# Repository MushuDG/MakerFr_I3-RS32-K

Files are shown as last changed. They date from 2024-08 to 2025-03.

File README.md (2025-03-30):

# 🚀 Upgrading the MakerFr I3-RS32: From SKR v1.4 to BTT Manta M5P + Klipper 🚀

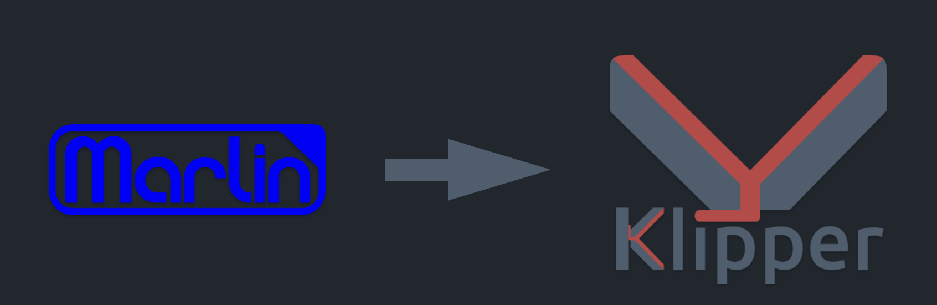
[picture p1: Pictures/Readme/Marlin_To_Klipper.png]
Marlin_To_Klipper


## 🌟 A Personal Note 🌟

Hey there, fellow 3D printing enthusiasts! 👋

After years of tinkering and printing with my trusty MakerFr I3-RS32 (an incredible Prusa like designed by RoMaker - [I3-RS32](https://www.makerfr.com/en/imprimante-3d/i3-rs32/presentation-de-la-i3rs32/)). I started to feel it was time for an upgrade. I’ve always loved tweaking my 3D printer, pushing its limits, and learning everything I can about the tech behind it. But lately, the SKR v1.4, while solid, just wasn’t cutting it anymore, and managing an external Raspberry Pi was getting... well, a bit cumbersome.

So, I decided it was time to dive into something new and exciting. I wanted a cleaner, more integrated setup, better performance, and—of course—a chance to dive deeper into the software side of things. That’s how this project was born: migrating from the SKR v1.4 to the **BTT Manta M5P** and switching from Marlin to **Klipper**. This isn’t just an upgrade; it’s a personal challenge to expand my skills and knowledge—and I’m excited to share this journey with you! 🎉

~ MushuDG

## Why Make the Switch? 🤔

1. **No More External Raspberry Pi! 🥳**

   - With the BTT Manta M5P, you get the power of a Raspberry Pi *built right in*. No more external boards cluttering up your setup—everything is clean and streamlined.
2. **Supercharge Your Firmware with Klipper 🚀**

   - Klipper isn’t just firmware—it’s a game-changer! Enjoy faster print speeds, higher precision, and advanced features that Marlin just can’t match. Discover what 3D printing can really do with Klipper’s real-time processing power.
3. **Simplified Setup & Greater Control 🎛️**

   - By upgrading to the Manta M5P, you’re moving to a modern, versatile board that simplifies your setup. And with Klipper, you’ll have unmatched control over your machine’s performance with a more intuitive configuration process.
4. **Future-Proof Your Printer 🔮**

   - The BTT Manta M5P is designed to support the latest innovations in 3D printing. This upgrade ensures that your MakerFr I3-RS32 stays ahead of the curve for years to come.
5. **A Learning Journey 🧠**

   - If you’re like me, you love to tinker and learn. This migration isn’t just about better prints—it’s about deepening your understanding of the software that drives your machine. Embrace the challenge and grow your skills!

## Parts and 3D Printed Parts 🛒

### Parts to Purchase

| Item | Price (USD) | Link |
|---|---|---|
| **BIGTREETECH Manta M5P** | ~$53.00 | [BIGTREETECH Manta M5P](https://biqu.equipment/products/manta-m4p-m8p?variant=40215552852066) |
| **BIGTREETECH CB1** | ~$30.00 | [BIGTREETECH CB1](https://biqu.equipment/products/manta-m4p-m8p?variant=39847241384034) |
| **BIGTREETECH CB1 Heatsink** | ~$5.50 | [BIGTREETECH CB1 Heatsink](https://biqu.equipment/products/manta-m4p-m8p?variant=39847241416802) |
| **Optional:** | | |
| **BIGTREETECH TFT35 SPI V2.1 Touch Screen** | ~$24.00 | [BIGTREETECH TFT35 SPI V2.1 Touch Screen](https://biqu.equipment/collections/lcd-screen/products/bigtreetech-tft35-spi-v2-1-touchscreen-io2can-module) |
| **Stylus for Touch Screen** | ~$1.10 | [Aliexpress Stylus](https://fr.aliexpress.com/item/1005006539716369.html?gatewayAdapt=glo2fra) |
| **Neopixel LEDs (1m 74 IP30 or 1m 144 IP30)** | ~$5.00| [Aliexpress Neopixel LEDs](https://fr.aliexpress.com/item/1005006224130239.html?gatewayAdapt=glo2fra) |
| **600mm SPI Cable** (choose Pitch 1.0mm; Direction Reverse; Length 600mm)  | ~$5.00| [eBay](https://www.ebay.fr/itm/253935636526?var=553252486969)

### 3D Printed Parts

| Item | Link |
|---|---|
| **Manta_M5P_Box.stl** | [Manta_M5P_Box.stl](https://github.com/MushuDG/MakerFr_I3-RS32-K/tree/main/STL) |
| **Manta_M5P_Cover.stl** | [Manta_M5P_Cover.stl](https://github.com/MushuDG/MakerFr_I3-RS32-K/tree/main/STL) |
| **Optional:** | |
| **TFT35-SPI.stl** | [TFT35-SPI.stl](https://github.com/MushuDG/MakerFr_I3-RS32-K/tree/main/STL) |
| **TFTholder.stl** | [TFTholder.stl](https://github.com/MushuDG/MakerFr_I3-RS32-K/tree/main/STL) |

## Ready to Dive In? 💻

In this documentation, I’ll guide you through the entire process—from hardware setup to firmware configuration. Whether you’re a seasoned maker or just curious, this guide has something for everyone. So, let’s get started and transform your 3D printing experience! 🔧✨

**Go to [Wiring](https://github.com/MushuDG/MakerFr_I3-RS32-K/blob/main/Documentation/1_Wiring.md)**

## 📜 License & Credits

This project is released under the **GNU General Public License v3.0**.

It includes modified code from the amazing project [Klipper Adaptive Meshing & Purging](https://github.com/kyleisah/Klipper-Adaptive-Meshing-Purging) by [@kyleisah](https://github.com/kyleisah), which is also licensed under **GPL-3.0**.

> Portions of the original code were adapted to fit the needs of this build, particularly in the context of bed mesh management and purge routines for the MakerFr I3-RS32 running Klipper.

Big kudos and thanks to Kyle for the original work and continued inspiration! 💜

---

**References:**

1. RoMaker. "[I3RS32 presentation](https://www.makerfr.com/en/imprimante-3d/i3-rs32/presentation-de-la-i3rs32/)." *MakerFr*.

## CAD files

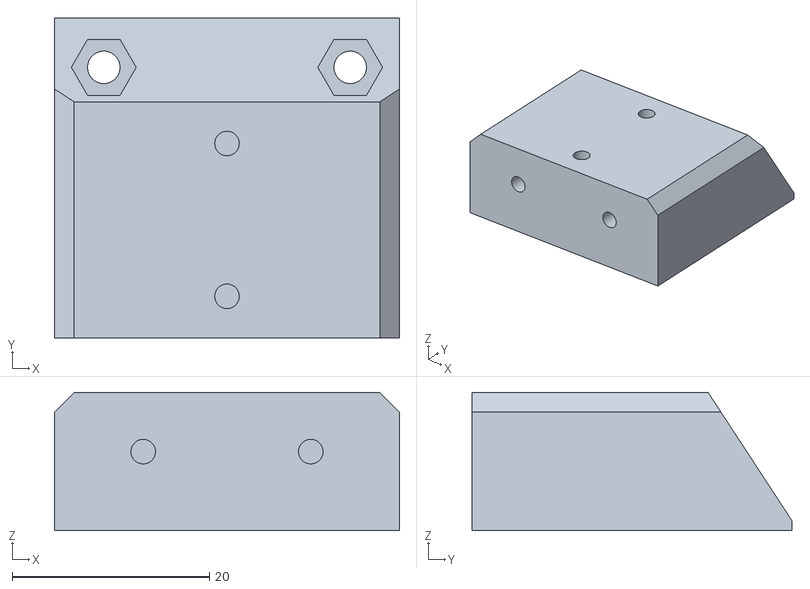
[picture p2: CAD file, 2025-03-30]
STL/BIQU_MicroProbe_holder.stl
35.0 x 32.5 x 14.0

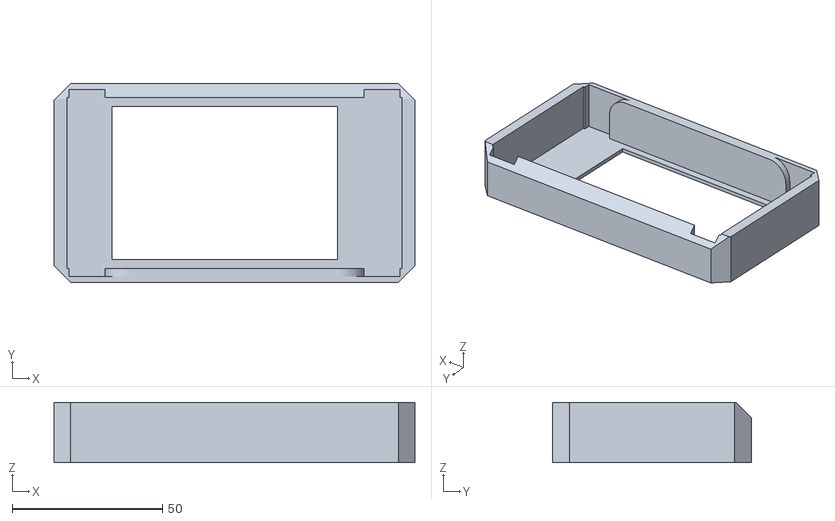
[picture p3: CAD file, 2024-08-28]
STL/TFT35-SPI.stl
120.0 x 66.0 x 20.0

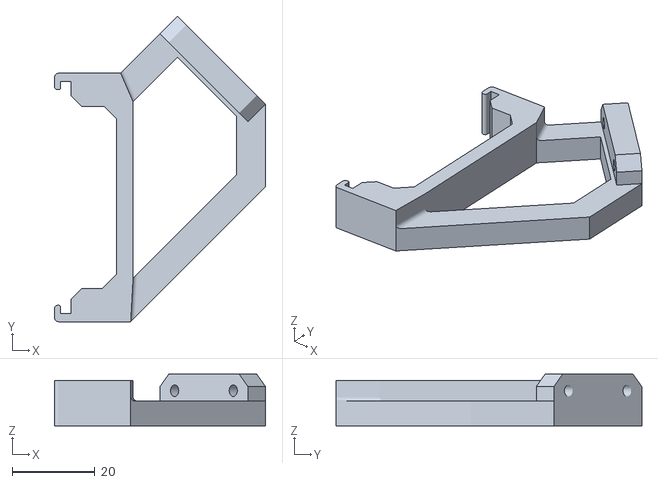
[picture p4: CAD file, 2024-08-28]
STL/TFTholder.stl
50.9 x 73.7 x 12.5

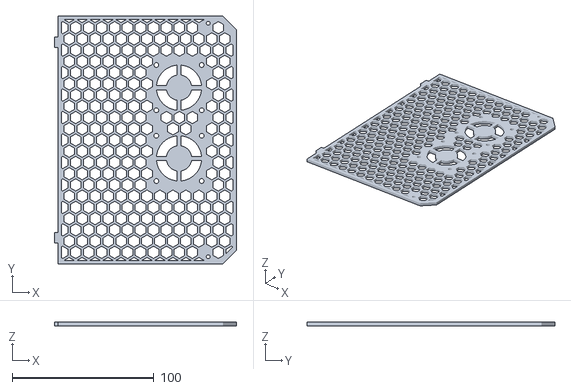
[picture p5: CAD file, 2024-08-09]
STL/Manta_M5P_Cover.stl
128.6 x 175.0 x 2.50

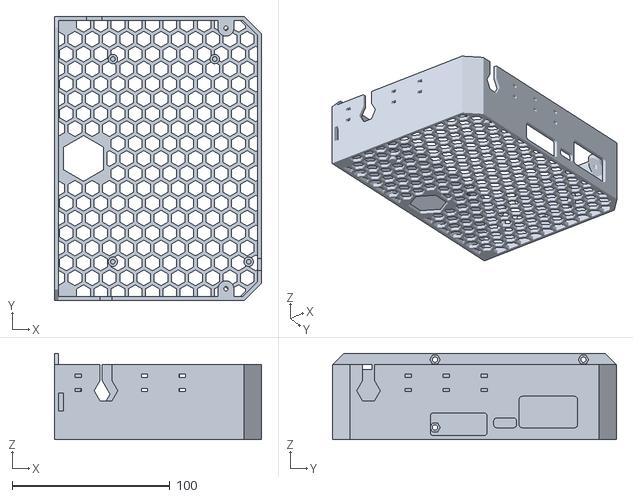
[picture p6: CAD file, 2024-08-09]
STL/Manta_M5P_Box.stl
131.1 x 180.0 x 54.7

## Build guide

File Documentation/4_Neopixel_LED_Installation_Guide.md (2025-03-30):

# 🌈 Neopixel LED Installation with Klipper on BTT Manta M5P

This guide will walk you through installing and configuring Neopixel LEDs on your BTT Manta M5P with Klipper. We’ll cover the physical installation, wiring, and configuring the Klipper firmware for dynamic LED control.

## Table of Contents
  1. [🔧 Materials Needed](#-materials-needed)
  2. [🛠️ Step 1: Physical Installation of LEDs](#️-step-1-physical-installation-of-leds)
  3. [🖥️ Step 2: Klipper Configuration for LEDs](#️-step-2-klipper-configuration-for-leds)
  4. [🚀 Step 3: Installing Klipper-LED\_Effect Plugin](#-step-3-installing-klipper-led_effect-plugin)
  5. [✅ Step 4: Testing and Verifying LED Installation](#-step-4-testing-and-verifying-led-installation)
  6. [📚 References](#-references)

## 🔧 Materials Needed

- **Neopixel LEDs** – *We used Black PCB, 1m 74 IP30, but feel free to choose your desired density (e.g., 144 LEDs/m).*
- **Wires** – *Three wires for power, ground, and signal.*
- **Soldering Kit** – *Ensure to solder correctly, following the directional arrow on the PCB!*
- **Connector JST** – *For connecting to the Manta board.*
- **BTT Manta M5P** – *Your baseboard where the LEDs will be connected.*

## 🛠️ Step 1: Physical Installation of LEDs

1. **Unboxing and Preparing LEDs**: Start by preparing your Neopixel LEDs. You can use 74 LEDs/m or opt for 144 LEDs/m for a more consistent lighting effect.
2. **Wiring and Soldering**: Solder the three wires to the LED strip, ensuring to follow the directional arrow on the PCB that indicates signal direction. 
    - **Common mistake**: Don’t solder on the wrong side (the direction of the arrow is crucial). 
3. **Connecting to the Manta Board**: 
    - Use a **JST connector** to hook up the LEDs directly to the **RGB1 port** of the Manta board:
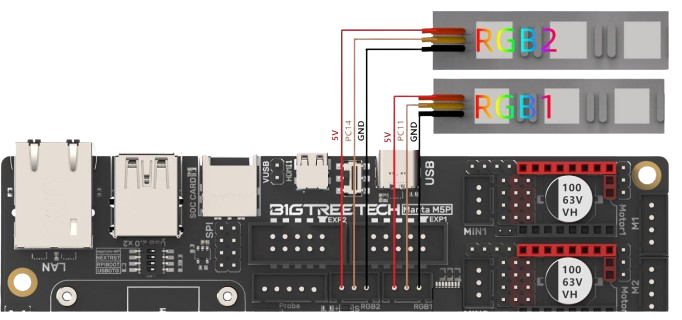
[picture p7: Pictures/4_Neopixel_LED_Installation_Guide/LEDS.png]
Manta_M5P_LEDS_Wiring


## 🖥️ Step 2: Klipper Configuration for LEDs

1. **Download the Configuration File**: Download the `leds.cfg` from this [GitHub link](https://raw.githubusercontent.com/MushuDG/MakerFr_I3-RS32-K/refs/heads/main/Klipper_Config/components_config/leds.cfg) and place it in the `~/printer_data/config/` directory.
2. **Edit printer.cfg**: 
    - In your `printer.cfg`, include the line `[include leds.cfg]` to load the LED configuration file. Uncomment this line by removing the `#`.
3. **Configure the LED settings**: In the `leds.cfg` file, adjust the following parameters:
    - **Pin**: Specify the pin depending on where the LEDs are connected. Use `PC11` for **RGB1** and `PC14` for **RGB2**.
    - **Chain Count**: Specify the number of LEDs in your chain. For example, `chain_count: 22`.

    ```ini
    pin: PC11  # Pin connected to the Neopixel LEDs.
    chain_count: 22  # Number of Neopixels in the chain.
    ```

## 🚀 Step 3: Installing Klipper-LED_Effect Plugin

1. **SSH into Your CB1**: Open a terminal and SSH into your CB1 board.
2. **Run the following commands** to clone and install the Klipper-LED_Effect plugin:

    ```bash
    cd ~
    git clone https://github.com/julianschill/klipper-led_effect.git
    cd klipper-led_effect
    ./install-led_effect.sh
    ```

3. **Configure LED Effects**: Follow the instructions in the Klipper-LED_Effect repository to set up and customize various LED effects.

## ✅ Step 4: Testing and Verifying LED Installation

1. **Restart Klipper**: Once everything is installed, restart Klipper for the changes to take effect.
2. **Test LED Operation**: Use commands in the Klipper console to check if the LEDs are functioning correctly. Adjust the effects or configurations as needed.
3. **Troubleshooting**: If the LEDs don’t light up or behave unexpectedly, double-check the wiring and ensure that the `leds.cfg` file is correctly configured.

Happy printing with your glowing setup! 🌟

**Optional: Go to [BTT TFT35 SPI installation](https://github.com/MushuDG/MakerFr_I3-RS32-K/blob/main/Documentation/5_BTT_TFT35_Installation_Guide.md)**

## 📚 References
1. [Klipper LED Effects Plugin Documentation](https://github.com/julianschill/klipper-led_effect)
2. [BTT Manta M5P Documentation](https://github.com/bigtreetech/Manta-M5P)

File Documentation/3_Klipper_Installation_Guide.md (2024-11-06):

# 🚀 Klipper Installation Guide via KIAUH

This guide will walk you through installing Klipper on your BTT CB1 with a BTT Manta M5P using KIAUH (Klipper Installation And Update Helper). Let's get started!

## Table of Contents
- [🚀 Klipper Installation Guide via KIAUH](#-klipper-installation-guide-via-kiauh)
  - [Table of Contents](#table-of-contents)
  - [🎯 Prerequisites](#-prerequisites)
  - [🛠️ Step 1: SSH into Your Machine](#️-step-1-ssh-into-your-machine)
  - [🧰 Step 2: Install Git](#-step-2-install-git)
  - [📥 Step 3: Clone the KIAUH Repository](#-step-3-clone-the-kiauh-repository)
  - [🚀 Step 4: Launch KIAUH](#-step-4-launch-kiauh)
  - [🔧 Step 5: Install Klipper](#-step-5-install-klipper)
  - [🌑 Step 6: Install Moonraker](#-step-6-install-moonraker)
  - [💧 Step 7: Install Fluidd](#-step-7-install-fluidd)
  - [🔧 Step 8: Configure Klipper](#-step-8-configure-klipper)
  - [🌐 Step 9: Access Fluidd](#-step-9-access-fluidd)
  - [⚙️ Step 10: Configure Fluidd for Klipper](#️-step-10-configure-fluidd-for-klipper)
  - [🔄 Step 11: Reboot and Test](#-step-11-reboot-and-test)
    - [Home Axes + Bed Mesh Calibration:](#home-axes--bed-mesh-calibration)
    - [Z-Tilt:](#z-tilt)
    - [PID Calibration for Hotend:](#pid-calibration-for-hotend)
    - [PID Calibration for Bed:](#pid-calibration-for-bed)
  - [🛠️ Step 12: Adjust the Z-Offset Using `PROBE_CALIBRATE`](#️-step-12-adjust-the-z-offset-using-probe_calibrate)
    - [Step 12.1: Open the Fluidd Interface](#step-121-open-the-fluidd-interface)
    - [Step 12.2: Start the Probe Calibration](#step-122-start-the-probe-calibration)
    - [Step 12.3: Adjust the Z-Offset](#step-123-adjust-the-z-offset)
    - [Step 12.4: Save the Calibration](#step-124-save-the-calibration)
    - [Step 12.5: Test the New Z-Offset](#step-125-test-the-new-z-offset)
  - [🛠️ Step 13: Calibrating Extruder Rotation Distance](#️-step-13-calibrating-extruder-rotation-distance)
    - [Initial Setup](#initial-setup)
    - [Step-by-Step Calibration](#step-by-step-calibration)
    - [Important Note](#important-note)
  - [🛠️ Step 14: Configuring Slicer](#️-step-14-configuring-slicer)
  - [References 📚](#references-)

## 🎯 Prerequisites

Before we begin, ensure you have the following:

- **BTT CB1 + BTT Manta M5P**: Your hardware should be set up and running a compatible Linux-based OS.
- **SSH Access**: Make sure SSH is enabled and you can connect to your system.

## 🛠️ Step 1: SSH into Your Machine

First, connect to your BTT CB1 via SSH:

```bash
ssh <username>@<IP_of_your_BTT_CB1>
```

Replace `<username>` with your actual username and `<IP_of_your_BTT_CB1>` with the IP address of your BTT CB1.

## 🧰 Step 2: Install Git

Ensure Git is installed on your machine:

```bash
sudo apt-get update
sudo apt-get upgrade
sudo apt-get install git -y
```

## 📥 Step 3: Clone the KIAUH Repository

Next, clone the KIAUH repository:

```bash
git clone https://github.com/th33xitus/kiauh.git
cd kiauh
```

## 🚀 Step 4: Launch KIAUH

Run KIAUH to open the installation menu:

```bash
./kiauh.sh
```

## 🔧 Step 5: Install Klipper

1. Select `Install Klipper` from the menu using `1` and `1` in the `[ Installation Menu ]`.
2. Select your preferred Python version. Use `1` for the recommended setting.
3. Select the number of Klipper instances to set up. The number of Klipper instances will determine the amount of printers you can run from the host. Select `1` to install 1 instance.

## 🌑 Step 6: Install Moonraker

1. From the `Installation Menu`, type `1` to start the installation process.
2. Select `2 [Moonraker]` to install Moonraker.
3. Enter `Y` to confirm the installation.

## 💧 Step 7: Install Fluidd

1. From the `Installation Menu`, type `1` to start the installation process.
2. Select `4 [Fluidd]` to install Fluidd.
3. Enter `Y` to confirm the installation.
4. Enter `Y` again when prompted to install the recommended macros.

## 🔧 Step 8: Configure Klipper

1. From the main menu, use `4` to enter the `Advanced Menu`.
2. Type `2` to enter the Klipper firmware building setup.
3. Enter these parameters:

```bash
[*] Enable extra low-level configuration options
    Micro-controller Architecture (STMicroelectronics STM32) --->
    Processor model (STM32G0B1) --->
    Bootloader offset (8KiB bootloader) --->
    Clock Reference (8 MHz crystal) --->
    Communication interface (USB (on PA11/PA12)) --->
```

4. Type `q` to quit and save the config. The building step will automatically be launched.
5. Type `3` in the `Advanced Menu`.
6. Type `1` to use the regular flashing method.
7. Type `1` to use `make flash`.
8. Type `1` to install in USB mode.
9. Enter your available MCU number and enter `Y` to continue.

   **Note:** After the writing is completed, there will be an error message: `dfu-util: Error during download get_status`, just ignore it.

## 🌐 Step 9: Access Fluidd

After everything is set up, you can access Fluidd from your web browser:

```http
http://<IP_of_your_BTT_CB1>
```

Replace `<IP_of_your_BTT_CB1>` with the actual IP address of your BTT CB1.

## ⚙️ Step 10: Configure Fluidd for Klipper

To configure Klipper with Fluidd, follow these steps:

1. Download the base configuration files:
   - [printer.cfg](https://github.com/MushuDG/MakerFr_I3-RS32-K/tree/main/Klipper_Config/base/printer.cfg)
   - [bed_mesh.cfg](https://github.com/MushuDG/MakerFr_I3-RS32-K/tree/main/Klipper_Config/base/bed_mesh.cfg)
   - [input_shaping.cfg](https://github.com/MushuDG/MakerFr_I3-RS32-K/tree/main/Klipper_Config/base/input_shaping.cfg)
   - [macros.cfg](https://github.com/MushuDG/MakerFr_I3-RS32-K/tree/main/Klipper_Config/base/macros.cfg)
   - [sensors.cfg](https://github.com/MushuDG/MakerFr_I3-RS32-K/tree/main/Klipper_Config/base/sensors.cfg)
   - [steppers.cfg](https://github.com/MushuDG/MakerFr_I3-RS32-K/tree/main/Klipper_Config/base/steppers.cfg)

2. Choose and download the configuration files for your specific components from the **components_config** folder:
   - [leds.cfg](https://github.com/MushuDG/MakerFr_I3-RS32-K/tree/main/Klipper_Config/components_config/leds.cfg) (if using Neopixel LEDs)
   - [tft35-v3.cfg](https://github.com/MushuDG/MakerFr_I3-RS32-K/tree/main/Klipper_Config/components_config/tft35-v3.cfg) (if using the BTT TFT35-V3.0 screen)
   - [tmc2208.cfg](https://github.com/MushuDG/MakerFr_I3-RS32-K/tree/main/Klipper_Config/components_config/tmc2208.cfg) (if using TMC2208 drivers)
   - [tmc2209.cfg](https://github.com/MushuDG/MakerFr_I3-RS32-K/tree/main/Klipper_Config/components_config/tmc2209.cfg) (if using TMC2209 drivers)

3. Upload the **printer.cfg** and all relevant included configuration files (including your chosen component files) to the following directory on your BTT CB1:
   ```bash
   /home/biqu/printer_data/config/
   ```

4. Make sure to adapt the `printer.cfg` file to your setup:
   - Adjust the `[mcu]` section with the correct serial ID of your MCU.
   - Include or comment out the relevant `include` statements based on your chosen hardware from the **components_config** directory.

   Example from `printer.cfg`:

   ```ini
   [include bed_mesh.cfg]
   [include input_shaping.cfg]
   [include macros.cfg]
   [include sensors.cfg]
   [include steppers.cfg]
   #[include leds.cfg]        # Uncomment if using Neopixel LEDs
   #[include tft35-v3.cfg]    # Uncomment if using BTT TFT35-V3.0 screen
   #[include tmc2208.cfg]     # Uncomment if using TMC2208 drivers
   [include tmc2209.cfg]      # Comment out if using TMC2208 drivers
   ```

5. To find your MCU serial ID, use this command via SSH:

   ```bash
   ls /dev/serial/by-id
   ```

6. Install KAMP in a `ssh` environment with the following command:
   ```bash
    cd
   
    git clone https://github.com/kyleisah/Klipper-Adaptive-Meshing-Purging.git
   
    ln -s ~/Klipper-Adaptive-Meshing-Purging/Configuration printer_data/config/KAMP

    cp ~/Klipper-Adaptive-Meshing-Purging/Configuration/KAMP_Settings.cfg ~/printer_data/config/KAMP_Settings.cfg
   ```
7. Open your `moonraker.conf` file and add this configuration:
   ```ini
   [update_manager Klipper-Adaptive-Meshing-Purging]
   type: git_repo
   channel: dev
   path: ~/Klipper-Adaptive-Meshing-Purging
   origin: https://github.com/kyleisah/Klipper-Adaptive-Meshing-Purging.git
   managed_services: klipper
   primary_branch: main
   ```

8. Open `KAMP_Settings.cfg` file delete and paste following content:
   ```ini
   [include ./KAMP/Adaptive_Meshing.cfg]       # Include to enable adaptive meshing configuration.
   #[include ./KAMP/Line_Purge.cfg]             # Include to enable adaptive line purging configuration.
   #[include ./KAMP/Voron_Purge.cfg]            # Include to enable adaptive Voron logo purging configuration.
   #[include ./KAMP/Smart_Park.cfg]             # Include to enable the Smart Park function, which parks the printhead near the print  area for final heating.

   [gcode_macro _KAMP_Settings]
   description: This macro contains all adjustable settings for KAMP 

   # The following variables are settings for KAMP as a whole.
   variable_verbose_enable: True               # Set to True to enable KAMP information output when running. This is useful for  debugging.

   # The following variables are for adjusting adaptive mesh settings for KAMP.
   variable_mesh_margin: 10                     # Expands the mesh size in millimeters if desired. Leave at 0 to disable.
   variable_fuzz_amount: 0                     # Slightly randomizes mesh points to spread out wear from nozzle-based probes. Leave at    0 to disable.

   # The following variables are for those with a dockable probe like Klicky, Euclid, etc.                 # ----------------  Attach  Macro | Detach Macro
   variable_probe_dock_enable: False           # Set to True to enable the usage of a dockable probe.      #   ---------------------------------------------
   variable_attach_macro: 'Attach_Probe'       # The macro that is used to attach the probe.               # Klicky Probe:    'Attach_Probe' | 'Dock_Probe'
   variable_detach_macro: 'Dock_Probe'         # The macro that is used to store the probe.                # Euclid Probe:    'Deploy_Probe' | 'Stow_Probe'
                                                                                                           # Legacy Gcode:    'M401'         | 'M402'

   # The following variables are for adjusting adaptive purge settings for KAMP.
   variable_purge_height: 0.8                  # Z position of nozzle during purge, default is 0.8.
   variable_tip_distance: 20                    # Distance between tip of filament and nozzle before purge. Should be similar to    PRINT_END final retract amount.
   variable_purge_margin: 60                   # Distance the purge will be in front of the print area, default is 10.
   variable_purge_amount: 30                   # Amount of filament to be purged prior to printing.
   variable_flow_rate: 12                      # Flow rate of purge in mm3/s. Default is 12.

   # The following variables are for adjusting the Smart Park feature for KAMP, which will park the printhead near the print area at a    specified height.
   variable_smart_park_height: 10              # Z position for Smart Park, default is 10.

   gcode: # Gcode section left intentionally blank. Do not disturb.

       {action_respond_info(" Running the KAMP_Settings macro does nothing, it is only used for storing KAMP settings. ")}

   ```

9. Once all files are uploaded and configured, restart Klipper and Fluidd from the web interface.

## 🔄 Step 11: Reboot and Test

Finally, reboot your BTT CB1 to ensure everything is set up correctly. After rebooting, test your setup by sending a command to your 3D printer via Fluidd.

You can test with the following commands:

### Home Axes + Bed Mesh Calibration:
```gcode
G28
BED_MESH_CALIBRATE
SAVE_CONFIG
```

### Z-Tilt:
```gcode
G28
Z_TILT_ADJUST
```

### PID Calibration for Hotend:
```gcode
PID_CALIBRATE HEATER=extruder TARGET=205
```

### PID Calibration for Bed:
```gcode
PID_CALIBRATE HEATER=heater_bed TARGET=65
```

## 🛠️ Step 12: Adjust the Z-Offset Using `PROBE_CALIBRATE`

Setting the correct Z-offset is crucial for achieving a perfect first layer. Here’s how to do it using the `PROBE_CALIBRATE` command directly from the Fluidd interface.

### Step 12.1: Open the Fluidd Interface

1. Access your Fluidd interface via your web browser.
2. Navigate to the **Console** tab.

### Step 12.2: Start the Probe Calibration

In the console, initiate the probe calibration process by entering:

```gcode
PROBE_CALIBRATE
```

This command will begin the process by homing the printer and then moving the probe to the center of the bed.

### Step 12.3: Adjust the Z-Offset

Once the probe is positioned, the nozzle will move down toward the bed. You need to manually adjust the Z-offset using the following command:

```gcode
TESTZ Z=-0.1
```

Keep sending the `TESTZ` command with small negative increments (e.g., `Z=-0.1`) until the nozzle is at the perfect distance from the bed. Use a piece of paper as a feeler gauge—when you feel slight resistance while moving the paper, you've found the correct offset.

### Step 12.4: Save the Calibration

After finding the right Z-offset, save the configuration with:

```gcode
ACCEPT
SAVE_CONFIG
```

The `ACCEPT` command will finalize the Z-offset setting, and `SAVE_CONFIG` will write this setting to your `printer.cfg` file.

### Step 12.5: Test the New Z-Offset

Finally, test your new Z-offset by printing a small test print to ensure the first layer adheres correctly. If further adjustments are needed, repeat the above steps.

## 🛠️ Step 13: Calibrating Extruder Rotation Distance

The `rotation_distance` of an extruder is the distance that the filament travels during one complete rotation of the stepper motor. To get this setting just right, it’s best to use a "measure and adjust" method. Here’s how:

### Initial Setup

1. **Estimate the Rotation Distance:** Start with an initial estimate of the `rotation_distance`. You can derive this from `steps_per_mm` or by inspecting your hardware.
   
2. **Prepare Your Printer:**
   - Make sure the extruder is loaded with filament.
   - Heat the hotend to the appropriate temperature.
   - Ensure your printer is ready to extrude.

### Step-by-Step Calibration

1. **Mark the Filament:**
   - Use a marker to place a mark on the filament approximately 70 mm from where it enters the extruder.
   - Use digital calipers to measure the exact distance from the mark to the extruder entrance. Record this as `initial_mark_distance`.

2. **Extrude Filament:**
   - In your printer’s console, run the following commands to extrude 50 mm of filament:
     ```
     G91
     G1 E50 F60
     ```
   - Record 50 mm as `requested_extrusion_distance`.
   - Wait for the extruder to complete the movement (about 50 seconds). Using a slow speed is crucial for accuracy, as faster speeds may cause high pressure, distorting your results. (Avoid using graphical interface extrude buttons for this test—they extrude too quickly.)

3. **Measure the Result:**
   - Use the calipers again to measure the new distance from the extruder entrance to the mark on the filament. Record this as `final_mark_distance`.
   - Calculate the actual amount extruded:  
     `actual_extrusion_distance = initial_mark_distance - final_mark_distance`

4. **Update the Rotation Distance:**
   - Calculate the new `rotation_distance` using:  
     `new_rotation_distance = previous_rotation_distance * actual_extrusion_distance / requested_extrusion_distance`
  - Round the new `rotation_distance` to three decimal places.

5. **Repeat if Necessary:**
   - If the `actual_extrusion_distance` differs from the `requested_extrusion_distance` by more than 2 mm, repeat the steps above to refine your calibration.

### Important Note

Avoid using the "measure and adjust" method for calibrating X, Y, or Z axes. This method isn’t precise enough for those axes and may lead to a suboptimal setup. For those, measure your belts, pulleys, and lead screws instead.

## 🛠️ Step 14: Configuring Slicer
1. Download and install the prusaslicer [I3-RS32 preset](https://github.com/MushuDG/MakerFr_I3-RS32-K/blob/main/PrusaSlicer_Config/I3-RS32-K_config_bundle.ini).

🎉 Congratulations! You've successfully installed Klipper on your BTT CB1 with a BTT Manta M5P using KIAUH. Enjoy the enhanced performance and capabilities Klipper brings to your 3D printing experience!

**Optional: Go to [Neopixel LEDs Installation Guide](https://github.com/MushuDG/MakerFr_I3-RS32-K/blob/main/Documentation/4_Neopixel_LED_Installation_Guide.md)**

## References 📚
1. [BigTreeTech Manta M5P Documentation](https://github.com/bigtreetech/Manta-M5P)
2. [Klipper3D Documentation](https://www.klipper3d.org)
3. RoMaker. "[I3RS32 settings](https://www.makerfr.com/imprimante-3d/i3-rs32/reglages-i3-rs32/)." *MakerFr*.

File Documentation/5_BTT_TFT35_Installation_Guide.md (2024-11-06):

# 🖥️ Integration of BTT TFT35 SPI V2.1 with BTT Manta M5P

This guide will help you successfully connect and configure your **BTT TFT35 SPI V2.1** touch screen with the **BTT Manta M5P**. We’ll go over the hardware setup, cabling, and software configuration, including calibration tips to avoid ghost touches.

## Table of Contents
- [🖥️ Integration of BTT TFT35 SPI V2.1 with BTT Manta M5P](#-integration-of-btt-tft35-spi-v21-with-btt-manta-m5p)
  - [🔧 Materials Needed](#-materials-needed)
  - [🛠️ Step 1: Hardware Installation](#%EF%B8%8F-step-1-hardware-installation)
  - [🔌 Step 2: Cable Length and Ghost Touch Issues](#-step-2-cable-length-and-ghost-touch-issues)
  - [📁 Step 3: Installing KlipperScreen](#-step-3-installing-klipperscreen)
  - [⚙️ Step 4: Screen Calibration](#%EF%B8%8F-step-4-screen-calibration)
  - [📚 References](#-references)

## 🔧 Materials Needed

1. **BTT TFT35 SPI V2.1 Touch Screen** – *This is the touch screen we will be using.*
2. **BTT Manta M5P Board** – *Your mainboard.*
3. **600mm SPI Cable** – *I recommend using a 600mm cable to avoid ghost touch issues due to interference.*
4. **Screwdriver, Wires, and Connectors** – *Standard tools for wiring and connection.*

## 🛠️ Step 1: Hardware Installation

1. **Mount the TFT35 Screen**: Securely mount the **TFT35 SPI V2.1** screen to your printer’s frame.
2. **Wiring**: Connect the screen to the **BTT Manta M5P** using the **SPI Screen** ports on both the screen and the board.
   - Use a **600mm SPI cable** to reduce the risk of interference (see the note below for more details on cable length).

## 🔌 Step 2: Cable Length and Ghost Touch Issues

When using a longer SPI cable (over 600mm), some users have reported **ghost touch issues**, which are caused by signal interference. To avoid this problem, it's best to stick to a **600mm cable**. If you need one, here is a recommended source:
- **600mm SPI Cable**: [eBay Link](https://www.ebay.fr/itm/253935636526?var=553252486969)

This should fix most interference issues.

## 📁 Step 3: Installing KlipperScreen

Once the hardware is set up and the screen is calibrated, we need to configure it in **Klipper**. **KIAUH** (Klipper Installation and Update Helper) makes it easy to install and configure KlipperScreen.

1. **SSH into your CB1**: Open a terminal and connect to your CB1 using SSH.
2. **Install KlipperScreen**:
    - Run the following command to start **KIAUH**:
    ```bash
    ./kiauh/kiauh.sh
    ```
    - In the main menu, type `1` to open the **Install Menu**, and type `5` to install KlipperScreen.
    - The tool will automate the process. Once completed, you'll see a success message.
3. **Restart Klipper**: After installation, restart Klipper, and you should see the TFT35 screen interface.

## ⚙️ Step 4: Screen Calibration

To improve the touch accuracy and avoid any ghost touches, it's important to **calibrate your screen**. Follow this official tutorial from **BTT** for calibrating your TFT35 SPI screen:

1. login into your CB1 via SSH
2. Install `xinput_calibrator`
```bash 
sudo apt update
sudo apt install xinput-calibrator
```
3. Query the ID of the touchscreen, The name of TFT35_SPI is ns2009 or TSC2007, as shown in the figure bellow the id is 6
```bash
DISPLAY=:0 xinput_calibrator --list
```
tft35_spi_id

4. Start calibration, Click on the center of the cross that appears one by one on the screen. Replace the id with the actual id found in the previous step. Record the parameters of `click 0 X`, `click 0 Y`, `click 3 X`, and `click 3 Y`, which are required for conversion.
```bash
DISPLAY=:0 xinput_calibrator -v --device <id>
```
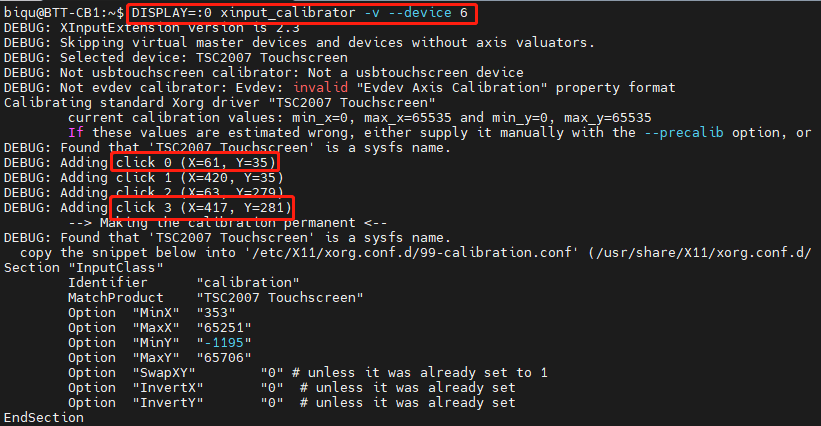
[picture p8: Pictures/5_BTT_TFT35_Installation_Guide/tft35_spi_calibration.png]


5. **!!! WARNING:** The parameter of `xinput_calibrator` cannot be directly used for `libinput` and needs to be converted. Please refer to here for details:
6. Create conversion script:
```bash
sudo nano libinput_calibrator.sh
```
7. Copy and paste the following content:

```bash
#!/bin/bash

#according to https://wiki.archlinux.org/title/Talk:Calibrating_Touchscreen#Libinput%5Fbreaks%5Fxinput%5Fcalibrator

screen_width=$1
screen_height=$2
click_0_X=$3
click_0_Y=$4
click_3_X=$5
click_3_Y=$6

re='^[0-9]+$'
if ! [[ $screen_width =~ $re ]] ; then
  echo "error: screen_width=\"$screen_width\" Not a number" >&2; exit 1
fi
if ! [[ $screen_height =~ $re ]] ; then
  echo "error: screen_height=\"$screen_height\" Not a number" >&2; exit 1
fi
if ! [[ $click_0_X =~ $re ]] ; then
  echo "error: click_0_X=\"$click_0_X\" Not a number" >&2; exit 1
fi
if ! [[ $click_0_Y =~ $re ]] ; then
  echo "error: click_0_Y=\"$click_0_Y\" Not a number" >&2; exit 1
fi
if ! [[ $click_3_X =~ $re ]] ; then
  echo "error: click_3_X=\"$click_3_X\" Not a number" >&2; exit 1
fi
if ! [[ $click_3_Y =~ $re ]] ; then
  echo "error: click_3_Y=\"$click_3_Y\" Not a number" >&2; exit 1
fi

#a = (screen_width * 6 / 8) / (click_3_X - click_0_X)
#c = ((screen_width / 8) - (a * click_0_X)) / screen_width
#e = (screen_height * 6 / 8) / (click_3_Y - click_0_Y)
#f = ((screen_height / 8) - (e * click_0_Y)) / screen_height

a=$(awk "BEGIN { printf(\"%.6f\", ($screen_width * 6 / 8) / ($click_3_X - $click_0_X))}")
c=$(awk "BEGIN { printf(\"%.6f\", (($screen_width / 8) - ($a * $click_0_X)) / $screen_width)}")
e=$(awk "BEGIN { printf(\"%.6f\", ($screen_height * 6 / 8) / ($click_3_Y - $click_0_Y))}")
f=$(awk "BEGIN { printf(\"%.6f\", (($screen_height / 8) - ($e * $click_0_Y)) / $screen_height)}")

CONFIG_OPTION="Option \"CalibrationMatrix\" "
CONFIG_LINE="\"$a 0.000000 $c 0.000000 $e $f 0.000000 0.000000 1.000000\""

echo "${CONFIG_OPTION}${CONFIG_LINE}"
echo ""

CONFIG_OPTION="Option \"CalibrationMatrix\" "
CONFIG="/usr/share/X11/xorg.conf.d/40-libinput.conf"
INPUT_CLASS="Identifier \"libinput touchscreen catchall\""
if [ -e "${CONFIG}" ]; then
    ks_restart=0
    grep -e "^\        ${CONFIG_OPTION}${CONFIG_LINE}" ${CONFIG} > /dev/null
    STATUS=$?
    if [ $STATUS -eq 1 ]; then
        sudo sed -i "/${CONFIG_OPTION}/d" ${CONFIG}
        sudo sed -i "/${INPUT_CLASS}/a\        ${CONFIG_OPTION}${CONFIG_LINE}" ${CONFIG}
        echo "Written to file:"
        echo "    ${CONFIG}"
        echo ""
        ks_restart=1
    fi

    # restart KlipperScreen
    if [ ${ks_restart} -eq 1 ];then
        sudo service KlipperScreen restart
    fi

    echo "run:"
    echo "    DISPLAY=:0 xinput list-props <device>"
    echo "to check if the calibration parameters are effective"
    echo ""
fi

```

8. Add executable permissions
```bash
sudo chmod +x libinput_calibrator.sh
```

9. Run the script with previous values in argument (got on point 4):

```bash
sudo ./libinput_calibrator.sh <screen width> <screen height> <click_0 X> <click_0 Y> <click_3 X> <click_3 Y>

```
Replace <arguments> with following values:
`<screen width>`: Screen horizontal resolution, TFT35 SPI is `480`
`<screen height>`: Screen vertical resolution, TFT35 SPI is `320`
`<click_0 X>`: The `X` position of `click 0` during the previous step calibration
`<click_0 Y>`: The `Y` position of `click 0` during the previous step calibration
`<click_3 X>`: The `X` position of `click 3` during the previous step calibration
`<click_3 Y>`: The `Y` position of `click 3` during the previous step calibration

for example:
```bash
sudo ./libinput_calibrator.sh 480 320 61 35 417 281
```

## 📚 References

1. [BTT TFT35 SPI V2.1 Documentation](https://bttwiki.com/tft35_spi_v2.1.html)
2. [BTT Manta M5P Documentation](https://github.com/bigtreetech/Manta-M5P)
3. [600mm SPI Cable on eBay](https://www.ebay.fr/itm/253935636526?var=553252486969)
4. [BTT Screen Calibration Guide](https://bttwiki.com/libinput_calibration.html)
5. [KlipperScreen Installation Guide](https://www.obico.io/blog/klipper-screen/)

Feel free to ask any questions or report issues in the [MakerFR forum](https://www.makerfr.com/forum/viewtopic.php?t=14710). Happy printing with your new touchscreen setup! 😊

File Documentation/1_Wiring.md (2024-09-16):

# 🛠️ MakerFr I3-RS32-K Wiring Guide

This guide will help you correctly connect all components to ensure your 3D printer functions optimally. Remember to double-check every connection before powering up, particularly the polarities, to avoid any potential damage. ⚠️

## Table of Contents
1. [Wiring Overview](#wiring-overview)
   - [Connection Table](#connection-table)
2. [Important Note 📌](#important-note-)
3. [Display Wiring](#display-wiring)
4. [Jumpers Configuration 🔧](#jumpers-configuration-)
   - [UART Mode of TMC Driver](#uart-mode-of-tmc-driver)
   - [Driver Voltage Selection](#driver-voltage-selection)
   - [CNC Fan Voltage Selection](#cnc-fan-voltage-selection)
5. [Additional Steps ✅](#additional-steps-)
6. [References 📚](#references-)

## Wiring Overview

Refer to the following diagram for the overall wiring layout:

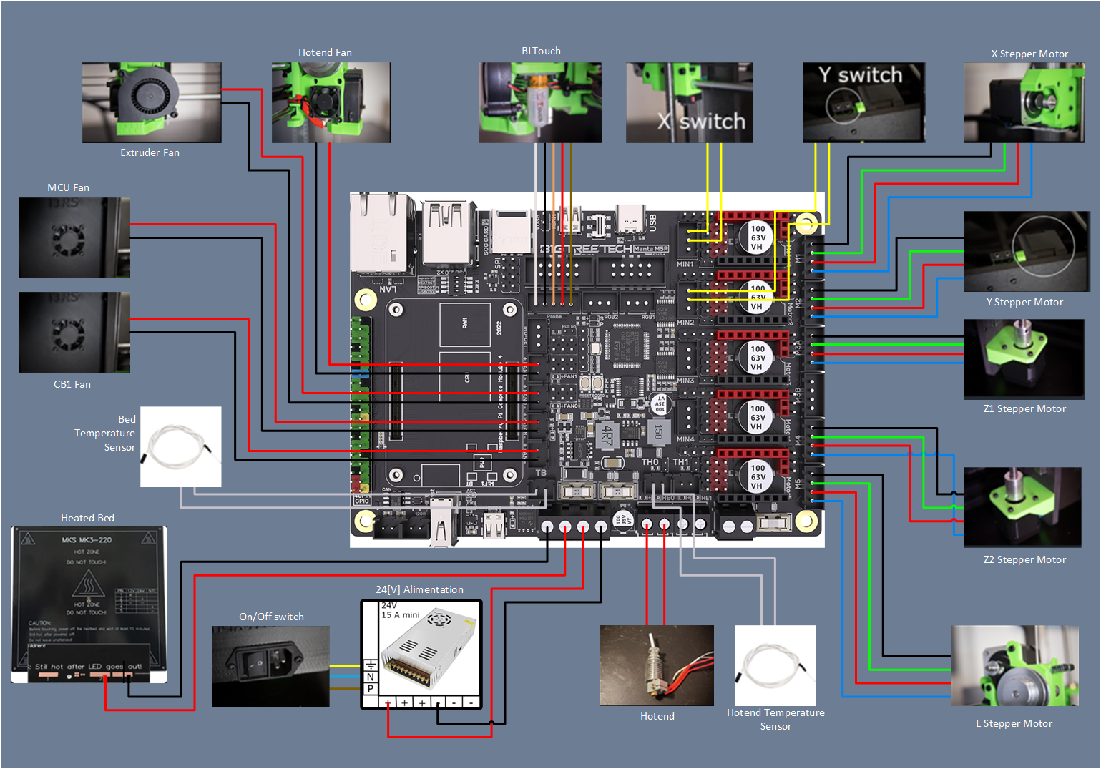
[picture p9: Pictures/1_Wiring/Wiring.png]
Manta_M5P_Wiring


### Connection Table

The table below provides detailed information on each connection point, including the pin or port, the connected component, its function, and the corresponding pinout.

| Pin/Port | Connected Component | Description | Pinout |
| --- | --- | --- | --- |
| **M1** | Motor 1 (X-Axis) | Stepper motor for X-Axis movement | PA15 (EN), PB9 (STEP), PC6 (DIR), PD9 (CS) |
| **M2** | Motor 2 (Y-Axis) | Stepper motor for Y-Axis movement | PA13 (EN), PA10 (STEP), PA14 (DIR), PB9 (CS)  |
| **M3A** | Motor 3A (Z-Axis) | Stepper motor for Z-Axis (Left) | PA9 (EN), PC7 (STEP), PC8 (DIR), PD8 (CS) |
| **M4** | Motor 4 (Z-Axis) | Stepper motor for Z-Axis (Right) | PA8 (EN), PB12 (STEP), PB11 (DIR), PB2 (CS) |
| **M5** | Motor 5 (Extruder) | Stepper motor for the extruder | PC4 (EN), PB0 (STEP), PB1 (DIR), PA6 (CS) |
| **MIN1** | X switch | Endstop switch for X-Axis | PD3 (GND), PA3 (5V), PA2 (Signal) |
| **MIN2** | Y switch | Endstop switch for Y-Axis | PD5 (GND), PA4 (5V), PA1 (Signal) |
| **HE0** | Hotend Heater | Heats the filament for extrusion | PA5 (VBB), PA7 (GND) |
| **TH0** | Hotend Thermistor | Measures the temperature of the hotend | PA1 (Signal), GND |
| **TB** | Bed Thermistor | Measures the temperature of the heated bed | PA0 (Signal), GND |
| **HV-IN**  | Power Input | 24V Power supply connection | HV+, HV- |
| **FAN0** | Part Cooling Fan | Fan for cooling the printed part | VBB (Power), PF3 (GND) |
| **FAN1** | Hotend Cooling Fan | Fan for cooling the hotend | VBB (Power), PF4 (GND) |
| **+FAN-**  | Electronics Cooling Fan | Fan for cooling the mainboard electronics  | VBB (Power), PF5 (GND) |
| **PI-FAN** | CB1 Cooling Fan | Fan for cooling the CB1 | VBB (Power), PF6 (GND) |
| **Probe**  | BLTouch | Used for automatic bed leveling | PA11 (Signal), PC15 (GND), PA6 (5V) |
| **HB** | Bed Heater | Power for the heated bed | PA5 (VBB), PA7 (GND) |

### Important Note 📌

The colors of the cables in the diagram can generally be trusted. However, the color order of stepper motor cables may vary depending on the manufacturer. Please ensure that the color sequence of your stepper motors matches the diagram or the pinout provided.

### Display Wiring

Connect the two EXP ports (EXP1, EXP2) to the TFT35 as shown in the diagram below:

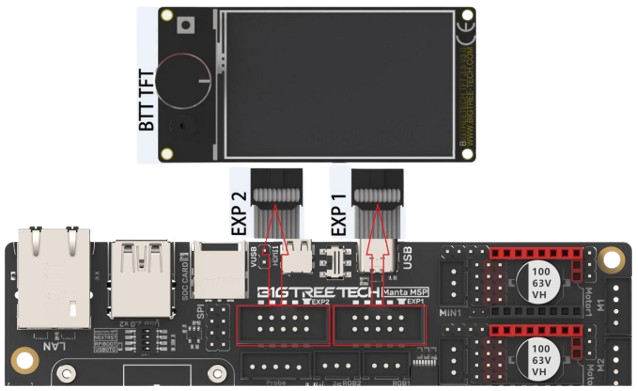
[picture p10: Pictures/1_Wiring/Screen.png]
Screen


## Jumpers Configuration 🔧

### UART Mode of TMC Driver

If you're using TMC2208, TMC2209, TMC2225, or similar drivers, ensure the jumpers are placed as shown in the diagram below. The microsteps and current settings can be configured within the firmware.

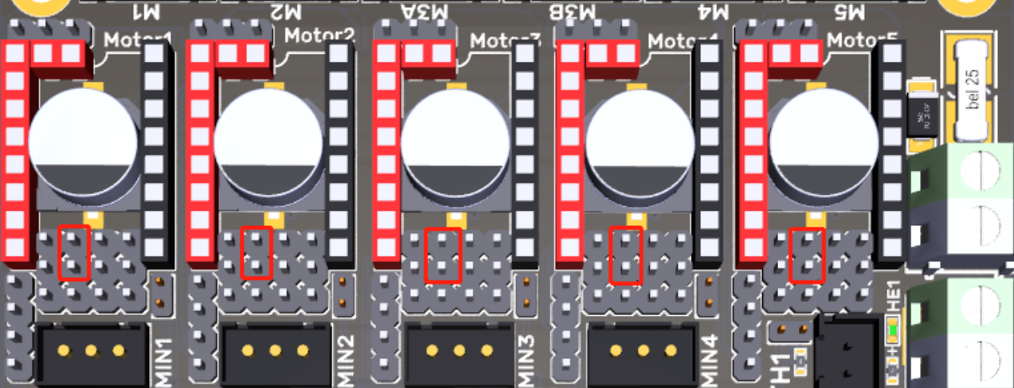
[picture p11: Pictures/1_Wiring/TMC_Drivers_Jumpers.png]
UART_TMC_Mode


### Driver Voltage Selection

Select the appropriate driver voltage according to your configuration needs. Use the following diagram as a guide:

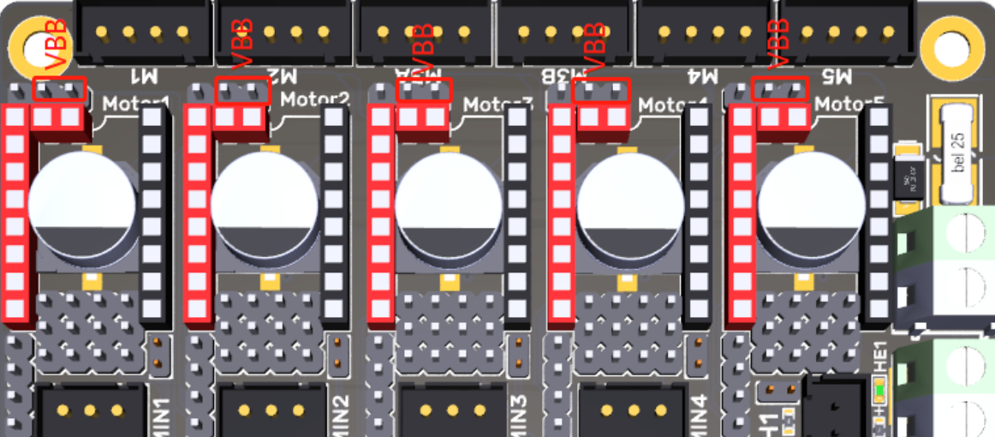
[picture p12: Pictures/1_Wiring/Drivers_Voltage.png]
Drivers_Voltage_Selection


### CNC Fan Voltage Selection

You can set the output voltage for the CNC fan to 24V, 12V, or 5V by adjusting the jumper cap accordingly.

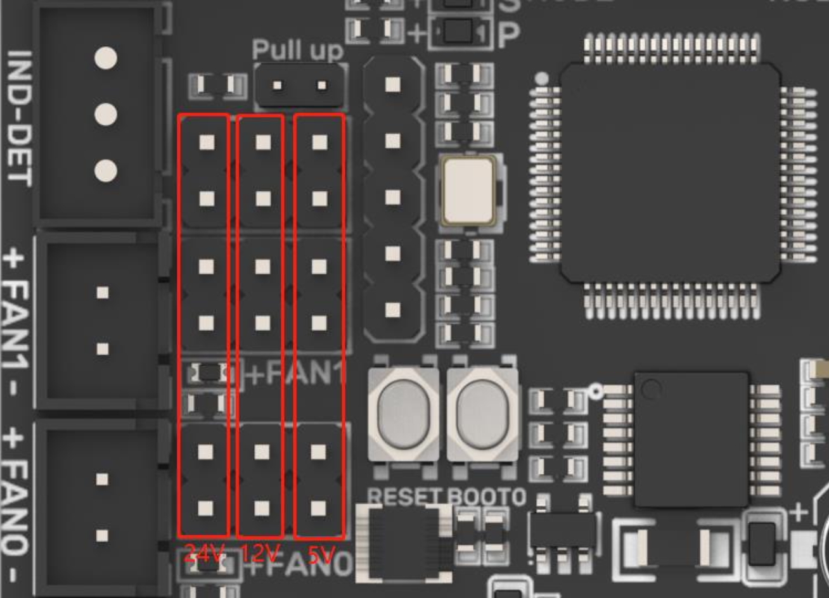
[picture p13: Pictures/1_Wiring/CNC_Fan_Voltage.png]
CNC_Fan_Voltage


## Additional Steps ✅

Once everything is wired and set up, the power supply should start up, and the 40mm fan in the case should begin to spin, indicating that the system is powered on correctly.

To proceed with the installation of the CB1 OS, please follow the instructions in the [CB1 OS Installation Guide](https://github.com/MushuDG/MakerFr_I3-RS32-K/blob/main/Documentation/2_CB1_OS_Installation.md).

## References 📚

1. RoMaker. "[I3RS32 wiring](https://www.makerfr.com/en/imprimante-3d/i3-rs32/cablage-i3rs32/)." *MakerFr*.
2. [BigTreeTech Manta M5P Documentation](https://github.com/bigtreetech/Manta-M5P)

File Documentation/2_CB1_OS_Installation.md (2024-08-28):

# 💾 CB1 OS Installation Guide

When using CB1, you can only download and install the OS image provided by BIGTREETECH. Please visit the following link to download the latest minimal version of Debian for CB1: [Download OS Image](https://github.com/bigtreetech/CB1/releases).

## Table of Contents
1. [Write OS 📝](#write-os-)
2. [WiFi Setting 📶](#wifi-setting-)
3. [Final Steps ✅](#final-steps-)
   - [Default SSH Credentials](#default-ssh-credentials)
4. [Additional Settings 🔐](#additional-settings-)
   - [Change Default Password](#change-default-password)
   - [Install ZSH for a Better Shell Experience 🐚](#install-zsh-for-a-better-shell-experience-)
5. [References 📚](#references-)

## Write OS 📝

Follow these steps to write the OS image to a MicroSD card:

1. Insert a MicroSD card into your computer via a card reader.
2. Choose OS.

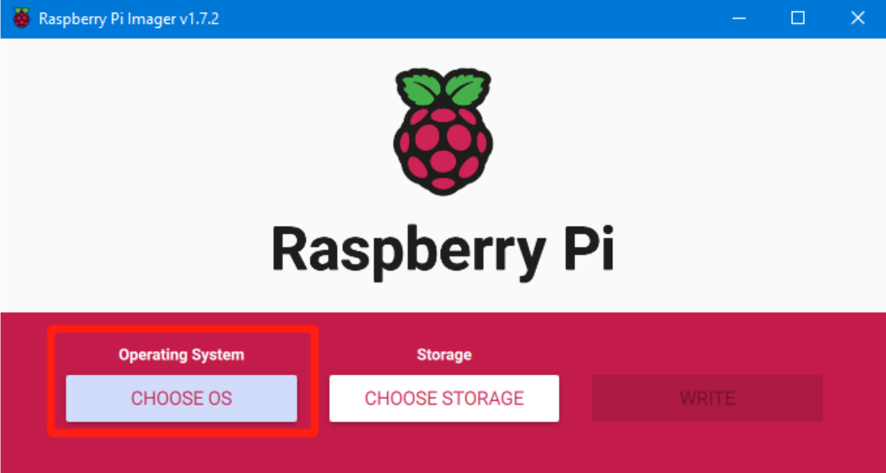
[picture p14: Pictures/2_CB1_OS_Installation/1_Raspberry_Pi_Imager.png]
   
3. Select "Use custom", then select the image that you downloaded.

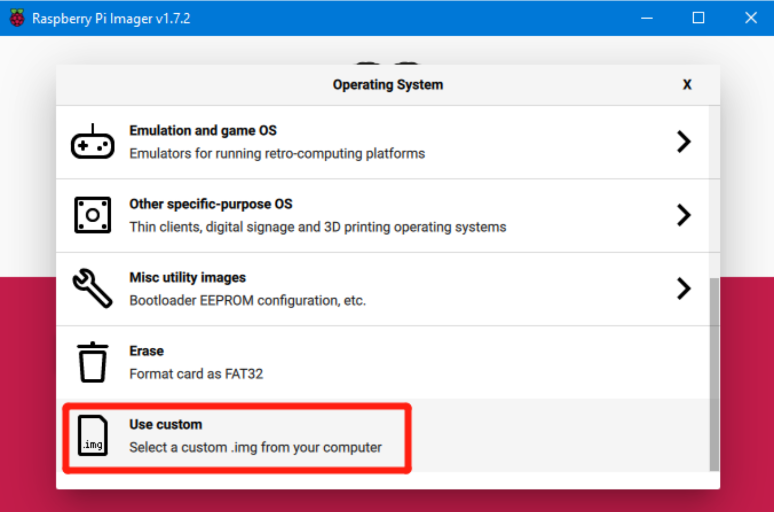
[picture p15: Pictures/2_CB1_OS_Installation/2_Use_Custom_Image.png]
   
4. Select the MicroSD card and click "WRITE". ⚠️ **Warning:** Writing the image will format the MicroSD card. Be careful not to select the wrong storage device, as this will result in data loss.

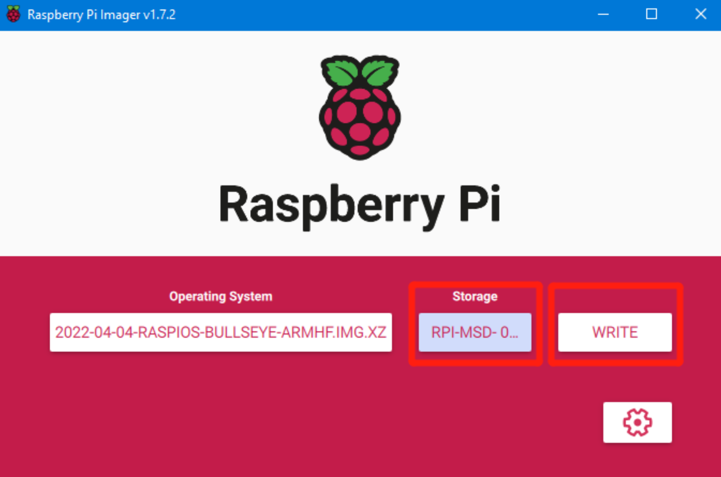
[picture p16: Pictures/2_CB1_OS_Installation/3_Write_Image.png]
   

## WiFi Setting 📶

Note: This step can be skipped if you are using a network cable connection.

CB1 cannot directly use the Raspberry Pi Imager to set the WiFi name and password like CM4. After the OS image writing is completed, the MicroSD card will have a FAT32 partition recognized by the computer. Locate the "system.cfg" file. Open it with your preferred text editor and set your WiFi credentials.

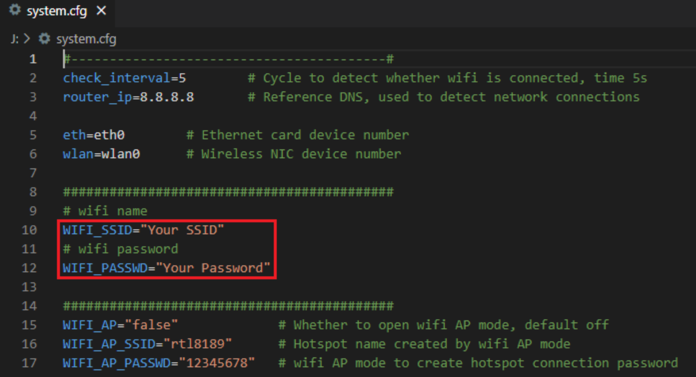
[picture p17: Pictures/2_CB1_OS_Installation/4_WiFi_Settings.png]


## Final Steps ✅

Insert the MicroSD card into the SoC SD port of the Manta M5P. Power on the main supply and wait for one to two minutes, then try to connect via SSH.

### Default SSH Credentials

- **Login as:** `biqu`
- **Password:** `biqu`

## Additional Settings 🔐

### Change Default Password

It's highly recommended to change the default password. Use the following command to do so:

```bash
biqu@BTT-CB1:~$ passwd
```

### Install ZSH for a Better Shell Experience 🐚

You can enhance your shell interface by installing ZSH using my [Bash-To-ZSH-Initialization](https://github.com/MushuDG/Bash-To-ZSH-Initialization) script. Run the following commands:

```bash
git clone https://github.com/MushuDG/Bash-To-ZSH-Initialization.git
chmod -R 740 ./Bash-To-ZSH-Initialization/
cd ./Bash-To-ZSH-Initialization
./install.sh
```

To proceed with the Klipper installation, please follow the instructions in the [Klipper Installation Guide](https://github.com/MushuDG/MakerFr_I3-RS32-K/blob/main/Documentation/3_Klipper_Installation_Guide.md).

## References 📚

1. [BigTreeTech Manta M5P Documentation](https://github.com/bigtreetech/Manta-M5P)

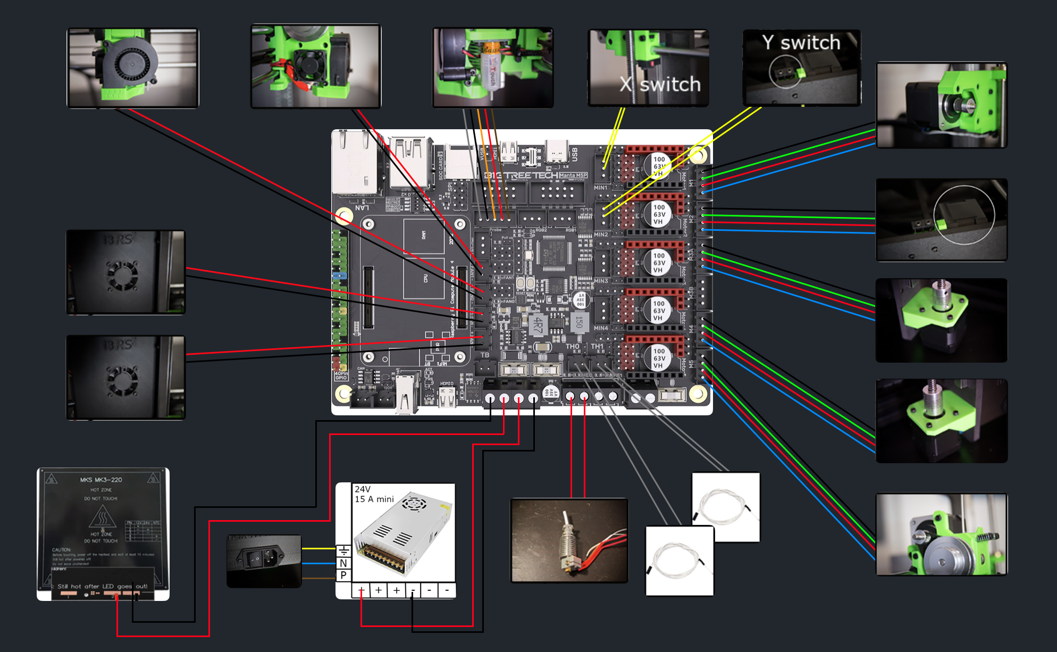
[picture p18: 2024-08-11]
Pictures/1_Wiring/Wiringg.png

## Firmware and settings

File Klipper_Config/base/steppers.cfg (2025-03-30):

################################################################################
# General Information
################################################################################
# Author:               MushuDG
# Project:              MakerFr_I3-RS32-K
# File:                 steppers.cfg
# Creation Date:        Sep. 12, 2024
# Modification Date:    Mar. 30, 2024
# Description:          Configuration file for stepper motors.
#                       This file includes settings for the X, Y, Z, and extruder motors,
#                       such as stepper pin assignments, microstepping, and endstop configurations.
################################################################################

########################################
# Stepper Motor Configurations
########################################

[stepper_x]
step_pin: PC8                          # Pin responsible for step signals to the motor.
dir_pin: PC9                           # Pin controlling the direction of the motor.
enable_pin: !PA15                      # Pin that enables/disables the motor (inverted signal).
microsteps: 16                         # Number of microsteps per full motor step.
rotation_distance: 32                  # Distance (mm) moved by one full motor rotation.
endstop_pin: !PD3                      # Pin connected to the X-axis endstop.
position_min: -11                      # Minimum allowable X-axis position.
position_endstop: -11                  # Position where the X-axis stops during homing.
position_max: 200                      # Maximum allowable X-axis position.
homing_speed: 60                       # Speed (mm/s) during X-axis homing.

[stepper_y]
step_pin: PA10                         # Pin responsible for step signals to the motor.
dir_pin: !PA14                         # Pin controlling the direction of the motor (inverted signal).
enable_pin: !PA13                      # Pin that enables/disables the motor (inverted signal).
microsteps: 16                         # Number of microsteps per full motor step.
rotation_distance: 32                  # Distance (mm) moved by one full motor rotation.
endstop_pin: !PD2                      # Pin connected to the Y-axis endstop.
position_min: -3                       # Minimum allowable Y-axis position.
position_endstop: -3                   # Position where the Y-axis stops during homing.
position_max: 215                      # Maximum allowable Y-axis position.
homing_speed: 60                       # Speed (mm/s) during Y-axis homing.

[stepper_z]
step_pin: PC6                          # Pin responsible for step signals to the motor.
dir_pin: PC7                           # Pin controlling the direction of the motor.
enable_pin: !PA9                       # Pin that enables/disables the motor (inverted signal).
microsteps: 16                         # Number of microsteps per full motor step.
rotation_distance: 8                   # Distance (mm) moved by one full motor rotation (smaller for precision).
endstop_pin: probe:z_virtual_endstop   # Virtual endstop using the probe for Z homing.
position_min: -10                      # Minimum allowable Z-axis position.
position_max: 210                      # Maximum allowable Z-axis position.
homing_speed: 10                       # Slower speed (mm/s) for precise Z-axis homing.

[stepper_z1]
step_pin: PB12                         # Pin responsible for step signals to the second Z motor.
dir_pin: PB11                          # Pin controlling the direction of the second Z motor.
enable_pin: !PA8                       # Pin that enables/disables the second Z motor (inverted signal).
microsteps: 16                         # Number of microsteps per full motor step.
rotation_distance: 8                   # Distance (mm) moved by one full motor rotation (matches primary Z).

[extruder]
step_pin: PB0                          # Pin responsible for step signals to the extruder motor.
dir_pin: PB1                           # Pin controlling the direction of the extruder motor.
enable_pin: !PC4                       # Pin that enables/disables the extruder motor (inverted signal).
microsteps: 16                         # Number of microsteps per full motor step.
rotation_distance: 6.06531             # Distance (mm) of filament extruded per motor rotation.
nozzle_diameter: 0.400                 # Diameter (mm) of the nozzle for calculating extrusion rates.
filament_diameter: 1.750               # Diameter (mm) of the filament being used.
max_extrude_only_distance: 150         # Maximum filament extrusion (mm) when not moving.
heater_pin: PC5                        # Pin controlling the extruder heater.
sensor_type: EPCOS 100K B57560G104F    # Thermistor type for measuring the extruder temperature.
sensor_pin: PA1                        # Pin connected to the thermistor for temperature readings.
min_temp: 0                            # Minimum allowable extruder temperature (°C).
max_temp: 250                          # Maximum allowable extruder temperature (°C).
max_extrude_cross_section: 5           # Limits cross-sectional area of extrusion to avoid over-extrusion.
pressure_advance: 0.074
#control: pid                          # Uncomment to enable PID temperature control.
#pid_Kp: 21.527                        # PID proportional gain.
#pid_Ki: 1.063                         # PID integral gain.
#pid_Kd: 108.982                       # PID derivative gain.

########################################
# Notes
########################################
# - Always calibrate rotation_distance for each stepper motor to ensure accurate movement.
# - Verify the wiring of stepper motors and endstops before running the printer.
# - Test homing and movement operations at low speeds to prevent mechanical damage.
# - Adjust nozzle_diameter and filament_diameter to match your hardware and materials.
# - PID tuning for the extruder heater ensures consistent temperatures for stable extrusion.

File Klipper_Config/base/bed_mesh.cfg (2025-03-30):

################################################################################
# General Information
################################################################################
# Author:               MushuDG
# Project:              MakerFr_I3-RS32-K
# File:                 bed_mesh.cfg
# Creation Date:        Sep. 12, 2024
# Modification Date:    Mar. 30, 2025
# Description:          Configuration file for bed mesh leveling.
#                       This file contains the settings for mesh probing and
#                       leveling compensation to ensure a flat printing surface.
################################################################################

########################################
# Bed Mesh Leveling
########################################
[bed_mesh]
# Bed mesh leveling creates a 3D map of the bed's surface, allowing the printer to adjust
# the Z height dynamically to compensate for any warping or unevenness.
algorithm: bicubic      # Interpolation method used to generate the mesh.
speed: 100              # Speed of the probe during bed leveling.
horizontal_move_z: 2    # Z-axis lift during horizontal movements to prevent nozzle collisions.
mesh_min: 15, 15        # Minimum X, Y positions for probing.
mesh_max: 185, 185      # Maximum X, Y positions for probing.
probe_count: 6, 6       # Number of probe points along the X and Y axes (creates a 5x5 grid).
fade_start: 0.5         # Z height at which fade begins (compensation gradually reduces).
fade_end: 15.0          # Z height at which mesh compensation is fully disabled.
bicubic_tension: 0.5    # Controls the smoothness of the mesh with the bicubic algorithm.

########################################
# Safe Z Homing
########################################
[safe_z_home]
# Safe Z homing moves the print head to the center of the bed before homing the Z axis.
# This prevents the nozzle from crashing into clips or other bed fixtures during homing.
home_xy_position: 110, 100    # Move to the center of the bed before homing Z.
speed: 50                     # Speed at which the print head moves to the homing position.
z_hop: 10                     # Lift the Z axis by 10 mm to avoid collisions during movement.
z_hop_speed: 20               # Speed for lifting the Z axis.

########################################
# Z-Tilt Adjustment
########################################
[z_tilt]
# Z tilt adjustment is used in dual Z motor setups to ensure the bed remains level between
# the two Z motors. It adjusts each motor independently based on probing results.
z_positions:
   -11,0                # X positions of the two Z motors.
   220,0
points:
   40,100               # Probe points used for tilt adjustment.
   140,100
speed: 200              # Speed during tilt adjustment.
horizontal_move_z: 5    # Z lift during movements to avoid collisions.
retries: 20             # Maximum number of retries if leveling is not successful.
retry_tolerance: 0.005  # The maximum allowed difference between measurements.

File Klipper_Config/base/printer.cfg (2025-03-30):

########################################
# Virtual SD Card Configuration
########################################
[virtual_sdcard]
# Path specifies the directory where G-code files are stored for virtual SD printing.
path: /home/biqu/printer_data/gcodes
# on_error_gcode defines the action to take if an error occurs during a print.
# CANCEL_PRINT stops the current print job safely.
on_error_gcode: CANCEL_PRINT

################################################################################
# General Information
################################################################################
# Author:               MushuDG
# Project:              MakerFr_I3-RS32-K
# File:                 printer.cfg
# Creation Date:        Aug. 28, 2024
# Modification Date:    Mar. 30, 2025
# Description:          Base configuration file for the MakerFr_I3-RS32-K 3D printer.
#                       It includes settings for kinematics, acceleration, velocity limits,
#                       and other essential parameters for printer operation.
################################################################################

########################################
# Include Additional Configuration Files
########################################
[include fluidd.cfg]           # Configuration for Fluidd web interface.
#[include adxl345_X.cfg]       # Optional: include ADXL345 accelerometer config for resonance testing.
[include KAMP_Settings.cfg]    # Settings specific to KAMP (Klipper Advanced Multi-Printer).
[include bed_mesh.cfg]         # Configuration for bed leveling using a mesh.
[include input_shaping.cfg]    # Input shaping to reduce print artifacts from mechanical resonance.
                                # Uncomment and ensure square_corner_velocity is set to 5.0.
[include macros.cfg]           # Contains custom G-code macros for advanced operations.
[include sensors.cfg]          # Configuration for sensors like temperature and filament runout.
[include steppers.cfg]         # Stepper motor settings (e.g., current, microsteps).
[include leds.cfg]             # Configuration for controlling Neopixel or other LEDs.
#[include tft35-v3.cfg]        # Uncomment if using the BTT TFT35 V3.0 touchscreen.
#[include tmc2208.cfg]         # Uncomment if using TMC2208 stepper motor drivers.
[include tmc2209.cfg]          # Configuration for TMC2209 stepper drivers. Comment out if using TMC2208.

########################################
# MCU Configuration
########################################
[mcu]
# MCU (Microcontroller Unit) is the brain of the printer. This section specifies
# its connection and communication settings.
serial: /dev/serial/by-id/usb-Klipper_stm32g0b1xx_24004C001950425938323120-if00
# Baud rate sets the communication speed between the host and MCU.
baud: 115200

########################################
# Printer Settings
########################################
[printer]
# Defines the kinematics or movement system. "cartesian" is for printers with rectangular beds.
kinematics: cartesian
# Maximum movement speed (in mm/s) for all axes.
max_velocity: 300
# Maximum acceleration (in mm/s²) for all axes. Higher values improve speed but can reduce print quality.
max_accel: 500
# Maximum Z-axis movement speed (in mm/s). Typically slower for precision layer adjustments.
max_z_velocity: 15
# Maximum Z-axis acceleration (in mm/s²). Lower values improve Z-axis precision.
max_z_accel: 100
# Speed at which the print head slows down for sharp corners, reducing artifacts.
square_corner_velocity: 5.0
# Note: Set square_corner_velocity to 5.0 if input shaping is enabled to optimize results.

########################################
# Pause and Resume
########################################
[pause_resume]
# recover_velocity sets the speed (in mm/s) at which printing resumes after a pause.
recover_velocity: 50.

########################################
# G-code Response Configuration
########################################
[respond]
# Enables the printer to send feedback or notifications to the user.

[exclude_object]
# Enables exclusion of specific objects during multi-object prints.
# Objects are defined in the G-code and can be canceled during printing.

#*# <---------------------- SAVE_CONFIG ---------------------->
#*# The contents are auto-generated.
#*#
#*# [bed_mesh default]
#*# version = 1
#*# points =
#*# 	  -0.451142, -0.398642, -0.413642, -0.369892, -0.347392, -0.316142, -0.307392, -0.348642
#*# 	  -0.462392, -0.463642, -0.463642, -0.429892, -0.437392, -0.378642, -0.356142, -0.377392
#*# 	  -0.478642, -0.446142, -0.444892, -0.421142, -0.368642, -0.334892, -0.316142, -0.354892
#*# 	  -0.486142, -0.476142, -0.474892, -0.441142, -0.419892, -0.413642, -0.363642, -0.369892
#*# 	  -0.462392, -0.446142, -0.403642, -0.356142, -0.349892, -0.343642, -0.318642, -0.356142
#*# 	  -0.452392, -0.447392, -0.433642, -0.422392, -0.401142, -0.369892, -0.363642, -0.354892
#*# x_count = 8
#*# y_count = 6
#*# mesh_x_pps = 2
#*# mesh_y_pps = 2
#*# algo = bicubic
#*# tension = 0.5
#*# min_x = 72.00699999999999
#*# max_x = 147.957
#*# min_y = 79.645
#*# max_y = 135.345
#*#
#*# [extruder]
#*# control = pid
#*# pid_kp = 23.244
#*# pid_ki = 1.490
#*# pid_kd = 90.652
#*#
#*# [heater_bed]
#*# control = pid
#*# pid_kp = 71.369
#*# pid_ki = 1.736
#*# pid_kd = 733.316
#*#
#*# [probe]
#*# z_offset = 0.879
#*#
#*# [input_shaper]
#*# shaper_type_x = mzv
#*# shaper_freq_x = 93.6
#*# shaper_type_y = 2hump_ei
#*# shaper_freq_y = 42.6

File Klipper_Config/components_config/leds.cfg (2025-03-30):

################################################################################
# General Information
################################################################################
# Author:               MushuDG
# Project:              MakerFr_I3-RS32-K
# File:                 leds.cfg
# Creation Date:        Sep. 12, 2024
# Modification Date:    Mar. 30, 2025
# Description:          
#   Configuration file for LED effects.
#   This file includes the settings for Neopixel LED control, including LED chains,
#   colors, and lighting effects based on different printer states (printing, heating, etc.).
################################################################################

########################################
# LED Configuration (Neopixels)
########################################
[neopixel leds]
pin: PC11                          # Pin connected to the Neopixel LEDs.
chain_count: 43                    # Number of Neopixels in the chain.
color_order: GRB                   # Order of color channels for the LEDs.
initial_RED: 0.0                   # Initial red channel brightness (0 = off).
initial_GREEN: 0.0                 # Initial green channel brightness (0 = off).
initial_BLUE: 0.0                  # Initial blue channel brightness (0 = off).

########################################
# LED Effects
########################################
# Define various LED effects for different printer states (e.g., heating, printing).

[led_effect led_static]
autostart: true                    # Automatically starts when the printer powers on.
leds: neopixel:leds                # Applies to the Neopixel LED group.
layers:
    static 1 0 top (0.0, 1.0, 0.267) # Static greenish light when idle or ready.

[led_effect breathing_effect]
autostart: false                   # This effect must be manually triggered.
frame_rate: 60                     # Speed of the breathing animation in frames per second.
leds: neopixel:leds                # Applies to the Neopixel LED group.
layers:
    breathing 12 0 top (1.0, 1.0, 0.0), (1.0, 1.0, 0.0) # Yellow breathing effect.

[led_effect heating_effect]
autostart: false                   # Manually triggered, usually linked to heating.
frame_rate: 24                     # Speed of the heating animation in frames per second.
heater: heater_bed                 # Links the effect to the bed heater.
leds: neopixel:leds                # Applies to the Neopixel LED group.
layers:
    heater 50 0 add (0, 0, 1), (1, 0, 0)  # Transition from blue (cold) to red (hot).

[led_effect printing_effect]
autostart: false                   # Effect triggered when the printer starts printing.
leds: neopixel:leds                # Applies to the Neopixel LED group.
layers:
    static 1 0 top (0.0, 0.5, 1.0) # Light blue color during printing.

[led_effect pause_effect]
autostart: false                   # Triggered when the printer is paused.
leds: neopixel:leds                # Applies to the Neopixel LED group.
layers:
    static 1 0 top (1.0, 1.0, 0.0) # Static yellow light during a pause.

[led_effect print_finished]
autostart: false                   # Triggered when the print finishes.
leds: neopixel:leds                # Applies to the Neopixel LED group.
layers:
    static 1 0 top (0.0, 1.0, 0.0) # Static green light when the print is finished.

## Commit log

2024-08-09 📖 DOC: Add .gitignore, update README with project details and personal note
2024-08-09 📦 NEW: Include STL files for new box and cover
    [Manta_M5P_Box.stl, Manta_M5P_Cover.stl]
2024-08-09 📦 NEW: Adding Marlin to Klipper Image
2024-08-09 📖 DOC: Enhance with pictures
2024-08-09 📖 DOC: Updating README DOC - Adding Wiring section - Adding CB1 OS Installation section - Adding Klipper installation section
2024-08-09 📦 NEW: adding generic config
    [generic-bigtreetech-manta-m5p.cfg]
2024-08-10 📖 DOC: Update Wiring guide
2024-08-10 📖 DOC: Update CB1 OS Installation Guide
2024-08-10 📖 DOC: Update doc klipper installation
2024-08-10 📦 NEW: Update config
    [printer.cfg]
2024-08-11 🐛 FIX: Updating printer.cfg
    [printer.cfg]
2024-08-11 🐛 FIX: Adding file type
2024-08-11 🐛 FIX: Update wiring doc
2024-08-11 🐛 FIX: Changing step/mm + adding TFT35 github issue
    [printer.cfg]
2024-08-11 👌 IMPROVE: printer config
    [printer.cfg]
2024-08-12 🐛 FIX: Adding baudrate
    [printer.cfg]
2024-08-12 📖 DOC: Update doc 3_Klipper_Installation_Guide.md
2024-08-12 🐛 FIX: Changing E0 dir pin
    [printer.cfg]
2024-08-12 📖 DOC: Adding Step 12 & 13
2024-08-12 🐛 FIX: Markdown titles
2024-08-12 🐛 FIX: Change E rotation distance
    [printer.cfg]
2024-08-12 📖 DOC: Adding step 14
2024-08-13 👌 IMPROVE: Update doc + printer.cfg
    [printer.cfg]
2024-08-16 📖 DOC: Updating doc 📦 NEW: Adding TMC2208 printer.cfg
    [generic-bigtreetech-manta-m5p.cfg, printer.cfg]
2024-08-21 📖 DOC: Update Klipper installation doc
2024-08-21 🐛 FIX: Fix printer.cfg configs
    [printer.cfg]
2024-08-21 🐛 FIX: Update printer.cfg configs
    [printer.cfg]
2024-08-28 📖 DOC: Updating docs
2024-08-28 👌 IMPROVE: Updating printers config files
    [printer.cfg]
2024-08-28 📦 NEW: Adding TFT35-SPI STL files
    [TFT35-SPI.stl, TFTholder.stl]
2024-08-28 🐛 FIX: Remove octoprint sec. + add Fluidd
2024-08-28 🐛 FIX: Fixing Table of Contents
2024-08-28 🐛 FIX: Add missing part
2024-08-28 🐛 FIX: Table of content
2024-08-29 👌 IMPROVE: Adding load and unload filament macros
    [printer.cfg]
2024-08-30 👌 IMPROVE: Adding parts and 3d printed parts
2024-08-30 🐛 FIX: Pin/port
2024-08-30 👌 IMPROVE: Move display
    [printer.cfg]
2024-09-03 🐛 FIX: Changing Gcode sec
2024-09-03 🐛 FIX: Current for TMC 👌 IMPROVE: Changing Z_Tilt
    [printer.cfg]
2024-09-03 📦 NEW: New tool to have a look on used port
2024-09-04 📖 DOC: Adding comments
    [printer.cfg]
2024-09-07 👌 IMPROVE: Add detailed comments to printer.cfg and include LED sections
    - Added extensive comments to each section of the printer.cfg file for better understanding.
    - Reorganized stepper motor, extruder, and TMC2209 driver configurations with clear explanations.
    - Documented MCU, bed heater, fan, and BLTouch settings.
    - Included input shaping and Z-tilt adjustment descriptions.
    - Expanded on G-code macros for common tasks (e.g., homing, bed leveling, filament handling).
    - Added LED configuration and macros for controlling LED effects (static, breathing, heating, printing, pause, and print finished).
    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
    [printer.cfg]
2024-09-12 👌 IMPROVE: Refactor Klipper configuration files and optimize structure
    - Added descriptive headers and comments for each configuration file (input_shaping.cfg, leds.cfg, tft35-v3.cfg, tmc2208.cfg, tmc2209.cfg, bed_mesh.cfg, macros.cfg, printer.cfg, sensors.cfg, steppers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
    - Improved clarity in comments for enabling/disabling specific configurations (LEDs, display, drivers).
    [bed_mesh.cfg, input_shaping.cfg, leds.cfg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]
2024-09-12 📖 DOC: Update Section 10 of Klipper Installation Guide
    - Added instructions for downloading and including specific component configuration files from components_config.
    - Clarified steps for selecting the appropriate configuration files (printer.cfg, leds.cfg, tft35-v3.cfg, tmc2208.cfg, tmc2209.cfg).
    - Provided an example of how to modify the printer.cfg to include or exclude files based on the user's hardware setup.
    - Improved guidance on finding MCU serial ID and restarting Klipper/Fluidd.
2024-09-12 🐛 FIX: Add header to macros.cfg file
    - Added a descriptive header to the macros.cfg file.
    - Included details about the author, project, file creation, and modification dates.
    - Clarified that the file contains G-code macros for automating tasks like homing, bed leveling, filament management, and LED control.
    [input_shaping.cfg, leds.cfg, macros.cfg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]
2024-09-15 👌 IMPROVE: Update cfg files
    [macros.cfg, printer.cfg]
2024-09-15 📖 DOC: Adding KAMP installation
2024-09-15 📦 NEW: Adding prusaslicer config bundle
2024-09-15 📖 DOC: Adding prusaslicer config bundle download link
2024-09-16 🐛 FIX: TB TH problem
    [sensors.cfg, steppers.cfg]
2024-09-18 📖 DOC: Update wiring pics
2024-09-23 🐛 FIX: Minor config bugs
    [macros.cfg, printer.cfg, sensors.cfg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]
2024-10-21 📦 NEW: Adding LED Installation tutorial
2024-10-21 👌 IMPROVE: Updating Readme
2024-10-21 📖 DOC: Updating parts
2024-10-21 📦 NEW: Adding Optional next step
2024-10-21 📖 DOC: Adding doc 5
2024-10-21 🐛 FIX: Redirect to doc 5 link
2024-10-21 🐛 FIX: Table of contents
2024-11-06 👌 IMPROVE: Starting gcode macro
    [macros.cfg]
2024-11-06 🐛 FIX: minor bug
2024-11-30 📖 DOC: update printer configuration files
    [bed_mesh.cfg, input_shaping.cfg, leds.cfg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]
2024-11-30 🐛 FIX: Prusa slicer bundle
2025-03-30 ✨ Configuration overhaul: Mesh leveling, macros, and slicer profiles
    🎯 Goal: Improve print quality, streamline daily use, and make the config cleaner & more modular.
    🔧 Mesh Bed Leveling
    - Switched to the “bicubic” algorithm for smoother, more accurate bed surface interpolation.
    - Fine-tuned tension settings to avoid bumpy first layers.
    - Adjusted probing points to better match the actual printable area.
    - More reliable homing sequence, with consistent Z repositioning.
    🧠 Klipper Macros
    - Complete refactor of startup (START_PRINT) and end (END_PRINT) macros for readability.
    - Clear step-by-step actions: purge, mesh, retract, fan control, etc.
    - Added inline comments to make ea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
    [Adaptive_Meshing.cfg, BIQU_MicroProbe_holder.stl, KAMP_Settings.cfg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]
2025-09-17 📦 NEW: PETG Profile Added
